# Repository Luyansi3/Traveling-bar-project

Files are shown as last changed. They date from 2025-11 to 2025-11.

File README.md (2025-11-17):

# 📷 Traveling Camera Bar Project -- Arduino & Python Control System (P2I-6)

This project implements a **motorized traveling bar** for camera motion,
controlled through a Python desktop interface.\
It combines an **Arduino Mega**, an **ESP8266 Feather Huzzah**, and a
**Python Tkinter GUI** to provide real-time control, video streaming,
object tracking, media recording, and automated timelapse scenarios.

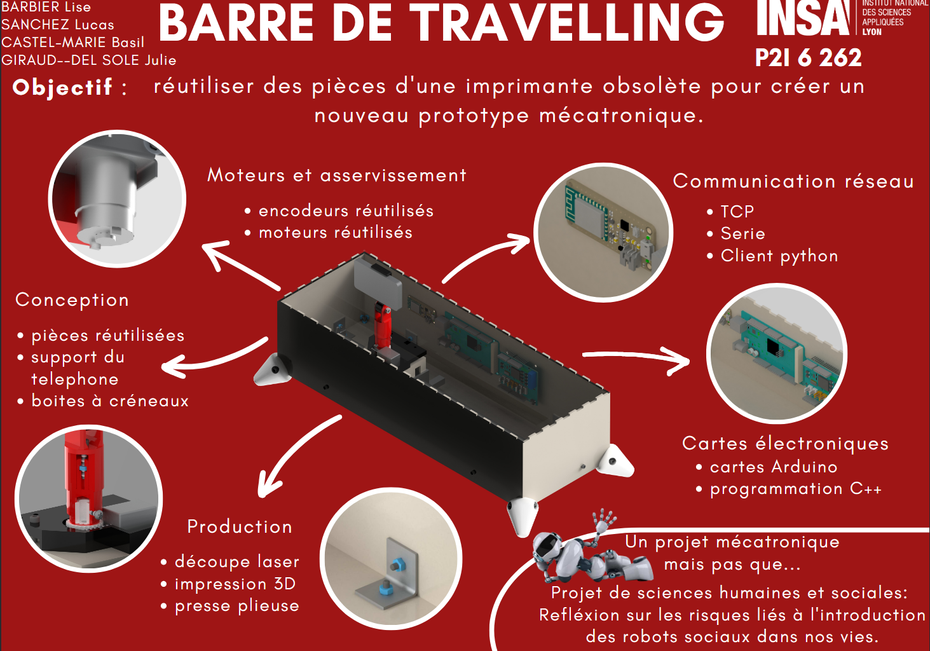
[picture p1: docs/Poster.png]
Poster


------------------------------------------------------------------------

## 🚀 Overview

The system allows precise **linear translation** and **rotation** of a
camera using two motors.\
A Python GUI connects to the ESP8266 over TCP and provides:

-   Manual control (translation & rotation)\
-   Real-time video display from an IP webcam\
-   Calibration of the linear rail\
-   Object detection & tracking (OpenCV HSV filtering)\
-   Photo & video recording\
-   Timelapse scenario automation\
-   Live feedback of motor positions from the Arduino Mega

Communication chain:

    PC (Python GUI) ⇄ TCP ⇄ ESP8266 (Wi-Fi) ⇄ Serial ⇄ Arduino Mega 2560

------------------------------------------------------------------------

# 🧠 System Architecture

## 1. Python Application (`Client.py`)

The Python program provides the full control interface.

### 🖥 `App` Class

Handles:

-   GUI (Tkinter)
-   TCP connection to ESP8266
-   Real-time video display (OpenCV)
-   Motor control buttons
-   Scenario builder (timelapse & video)
-   Threaded message reception from ESP8266
-   Object detection & tracking
-   Media recording (photos/videos)

Commands sent to the ESP8266 all begin with a structured header, for
example:

    /MEGA /MOTORA <speed>;
    /MEGA /POS ...
    /MEGA /TL <posA> <posB>;

### 📸 `MyCamera` Class

Responsible for:

-   Connecting to the IP webcam (iVCam or local webcam)
-   Returning raw frames to the UI
-   Writing video files
-   Saving photos
-   Managing resolution, FPS, and codec (XVID)

------------------------------------------------------------------------

## 2. ESP8266 Program (`Code_ESP.ino`)

The Feather Huzzah acts as a **TCP server**.

Its responsibilities:

-   Connect to a configured Wi-Fi network\
-   Accept incoming TCP connections from the PC\
-   Create a **serial bridge** between Python and the Arduino Mega\
-   Forward commands and feedback in both directions\
-   Identify and forward messages using headers:
    -   `/ORDI` → PC → Mega\
    -   `/MEGA` → Mega → PC

The ESP uses **SoftwareSerial** on pins 13 and 15 because I²C
communication was unreliable.

------------------------------------------------------------------------

## 3. Arduino Mega Program (`Code_MEGA.ino`)

The Mega manages the motors and reads the encoders.

Main features:

### 🧭 Calibration

-   Moves the motor until the mechanical limit is reached\
-   Detects plateau in encoder readings\
-   Sets the encoder value to **0** (translation origin)

### ⚙️ Motor Control

Receives commands such as:

    /MOTORA <speed>;
    /MOTORB <speed>;
    /TL <posA> <posB>;

Then:

-   Converts centimeters to encoder units\
-   Ensures setpoints remain in safe range\
-   Applies **P-control** (future upgrade to PI-control)\
-   Sends back motor position every 2 seconds using:

```
    /POSA <value>
    /POSB <value>
```

------------------------------------------------------------------------

# 📡 Communication Protocols

### **1. TCP (PC ↔ ESP8266)**

-   PC is the client\
-   ESP8266 is the server\
-   Allows command transmission & status feedback

### **2. Serial (ESP8266 ↔ Arduino Mega)**

-   Implemented via SoftwareSerial\
-   Required because I²C was unreliable\
-   Header-based routing

Example:

    /ORDI /MOTORA 120;

### **3. IP Webcam (PC ↔ Smartphone)**

The Python app retrieves the video stream using OpenCV from iVCam.

------------------------------------------------------------------------

# 🕹 Python GUI Features

### ✔ Manual Control

-   Translate left/right\
-   Rotate left/right\
-   Adjustable motor speed\
-   Progressive acceleration & deceleration for smooth motion

### ✔ Calibration

-   Automatic zeroing of the translation axis

### ✔ Real-Time Video + Object Tracking

-   HSV-based color detection\
-   On-frame markers\
-   Automatic correction commands sent every 300 ms

### ✔ Timelapse Generator

-   Define duration\
-   Select total rotation\
-   Set time interval between photos\
-   Automated movement + shooting\
-   Progress bar showing carriage movement

### ✔ Media Recording

-   Take photos (JPG)\
-   Start/stop video recording (AVI)

------------------------------------------------------------------------

# 📁 Project Structure

    /Client.py        → Python GUI
    /Code_MEGA.ino    → Arduino Mega firmware
    /Code_ESP.ino     → ESP8266 firmware

------------------------------------------------------------------------

# 🛠 Hardware Requirements

-   Arduino Mega 2560\
-   ESP8266 Feather Huzzah\
-   2× DC motors with motor drivers\
-   Linear rail + rotary stage\
-   Encoders\
-   Smartphone (iVCam) or USB webcam\
-   Computer with Python 3

------------------------------------------------------------------------

# 🧩 Software Requirements

### **Python**

-   Python 3.8+
-   Tkinter
-   OpenCV
-   Numpy
-   PIL (Pillow)

### **Arduino**

-   SoftwareSerial\
-   Encoder library\
-   WiFi libraries for ESP8266

------------------------------------------------------------------------

# ▶ How to Run

### **1. Flash the boards**

Upload: - `Code_MEGA.ino` to the Arduino Mega\
- `Code_ESP.ino` to the ESP8266

### **2. Connect devices to the same Wi-Fi network**

(iVCam phone + PC + ESP8266)

### **3. Run the Python app**

``` bash
python Client.py
```

### **4. Enter the ESP8266 IP address in the GUI**

Click **Connect**.

### **5. Start moving the camera!**

------------------------------------------------------------------------

# 📸 Media & Documentation

## 🔌 Wiring Diagram

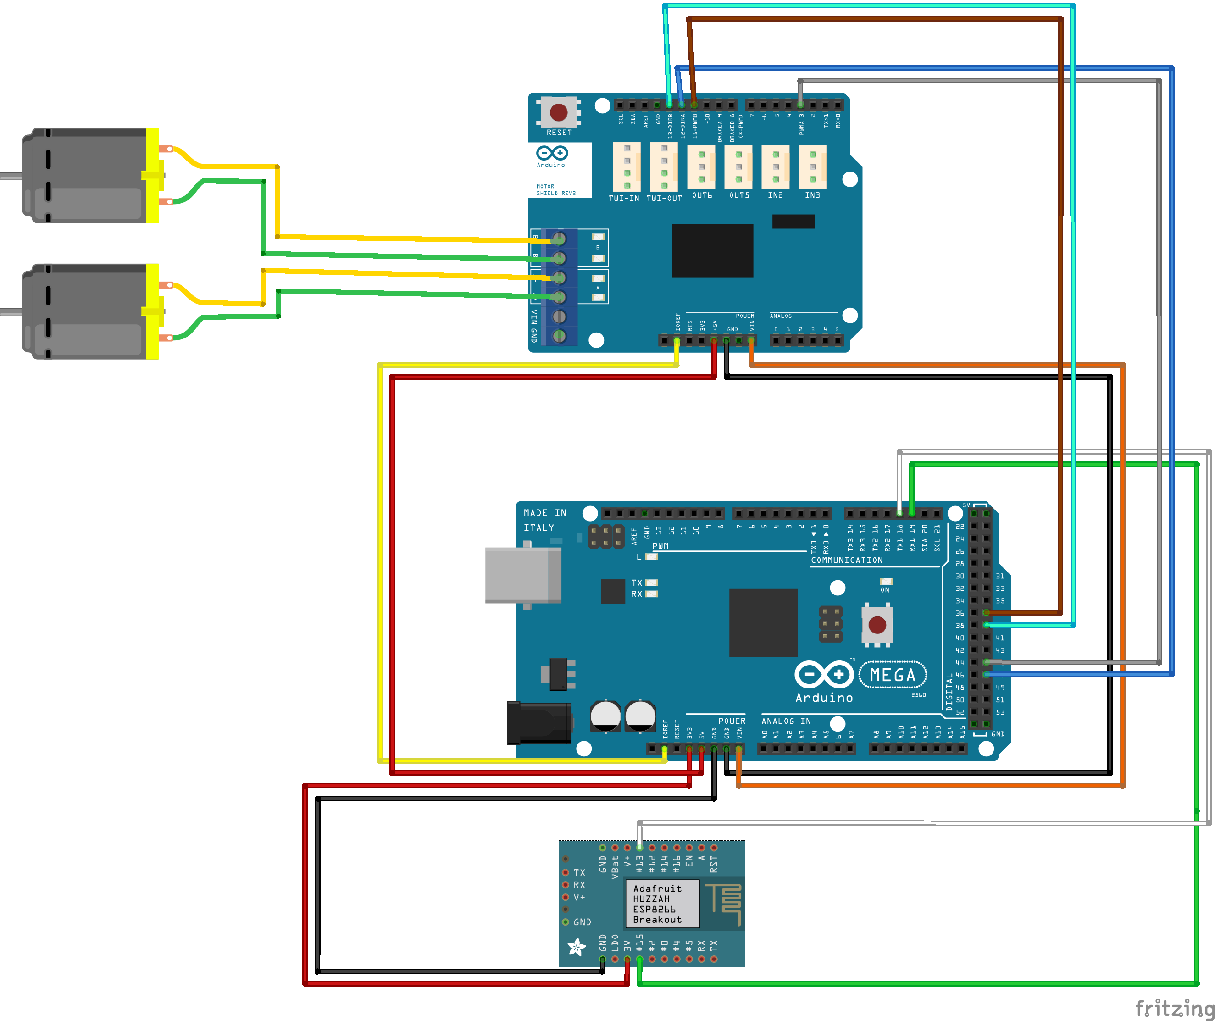
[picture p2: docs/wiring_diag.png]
Wiring Diagram


## 🎬 Demonstration Video

Demo Video

------------------------------------------------------------------------

# 🛠 Future Improvements

-   Upgrade P-control to PI-control\
-   Better object-tracking using ML models\
-   Stabilization algorithms\
-   Automatic timelapse video generation\
-   GUI redesign with PyQt or custom widgets

------------------------------------------------------------------------

# 🙌 Contributors

Lise Barbier, Basile Castel-Marie, Julie Giraud--Del Sole & Lucas Sanchez.

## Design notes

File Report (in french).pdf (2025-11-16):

# P2i6 – 262 : Réemploi d’imprimantes

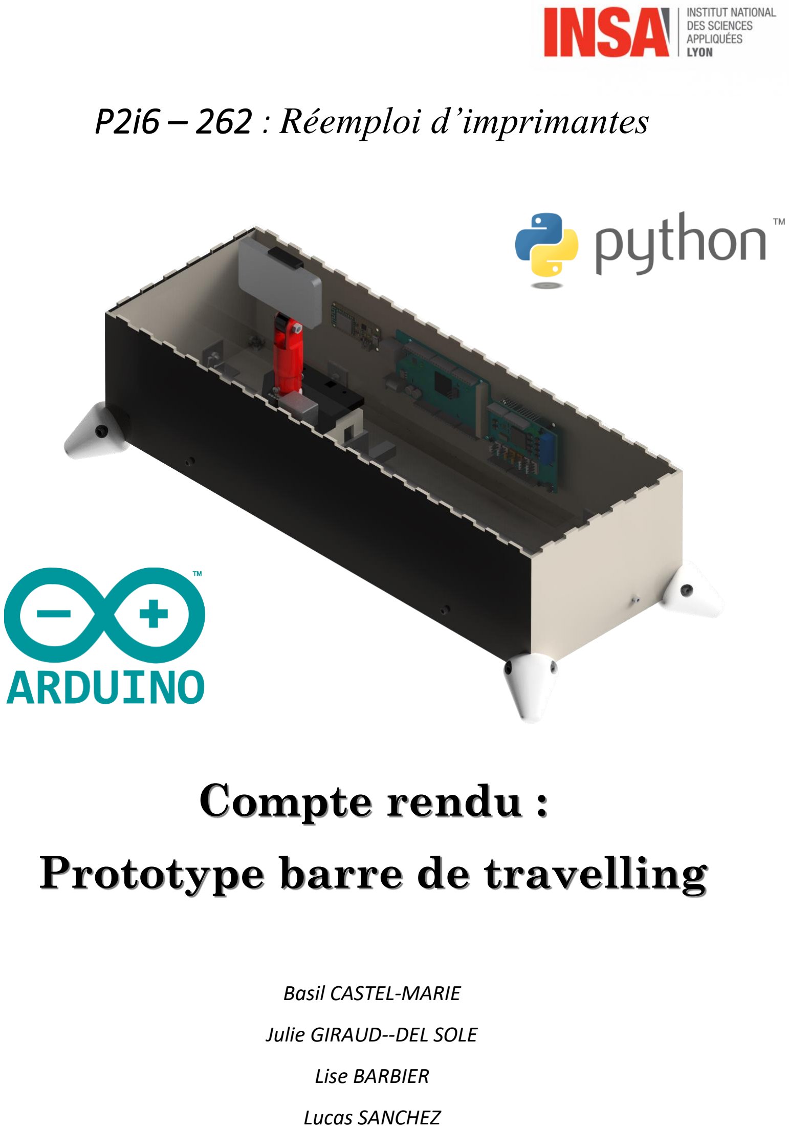
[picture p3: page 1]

# Compte rendu :

# Prototype barre de travelling

### Basil CASTEL-MARIE

### Julie GIRAUD--DEL SOLE

### Lise BARBIER

### Lucas SANCHEZ

Basil CASTEL-MARIE Julie GIRAUD--DEL SOLE Lucas SANCHEZ Lise BARBIER

Page 1 sur 19

## Compte rendu P2i6 : Barre de travelling

## Table des matières

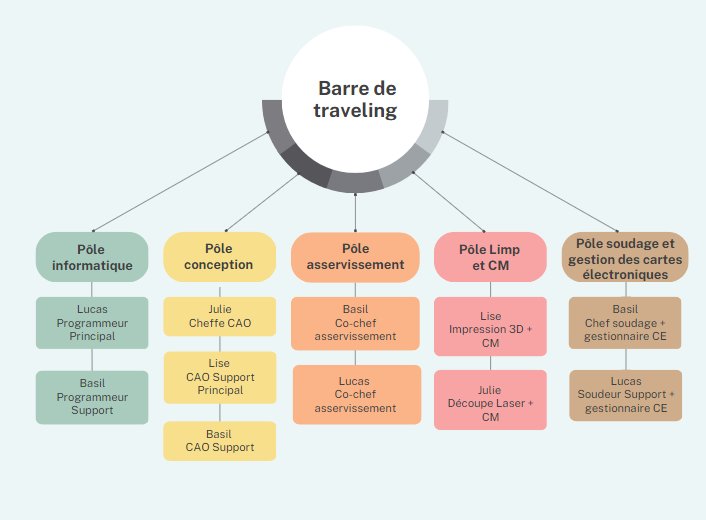
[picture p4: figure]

Page 2 sur 19

## I. Objectif

Notre objectif était de créer une barre de travelling utilisable avec un smartphone. Le smartphone doit pouvoir prendre des vidéos en effectuant un déplacement transversal et une rotation sur lui-même (asservissement des moteurs). Les mouvements du support de smartphone doivent être pilotés à distance sur un ordinateur (communication réseau TCP et série).

## II. Organigramme du groupe

## III. Journal de suivi

Remarque : Ce journal de suivi ne donne qu’une idée générale de la répartition des tâches au cours des séances et n’est pas exhaustif. Chaque membre du groupe a été totalement impliqué pour mener à bien ce projet.

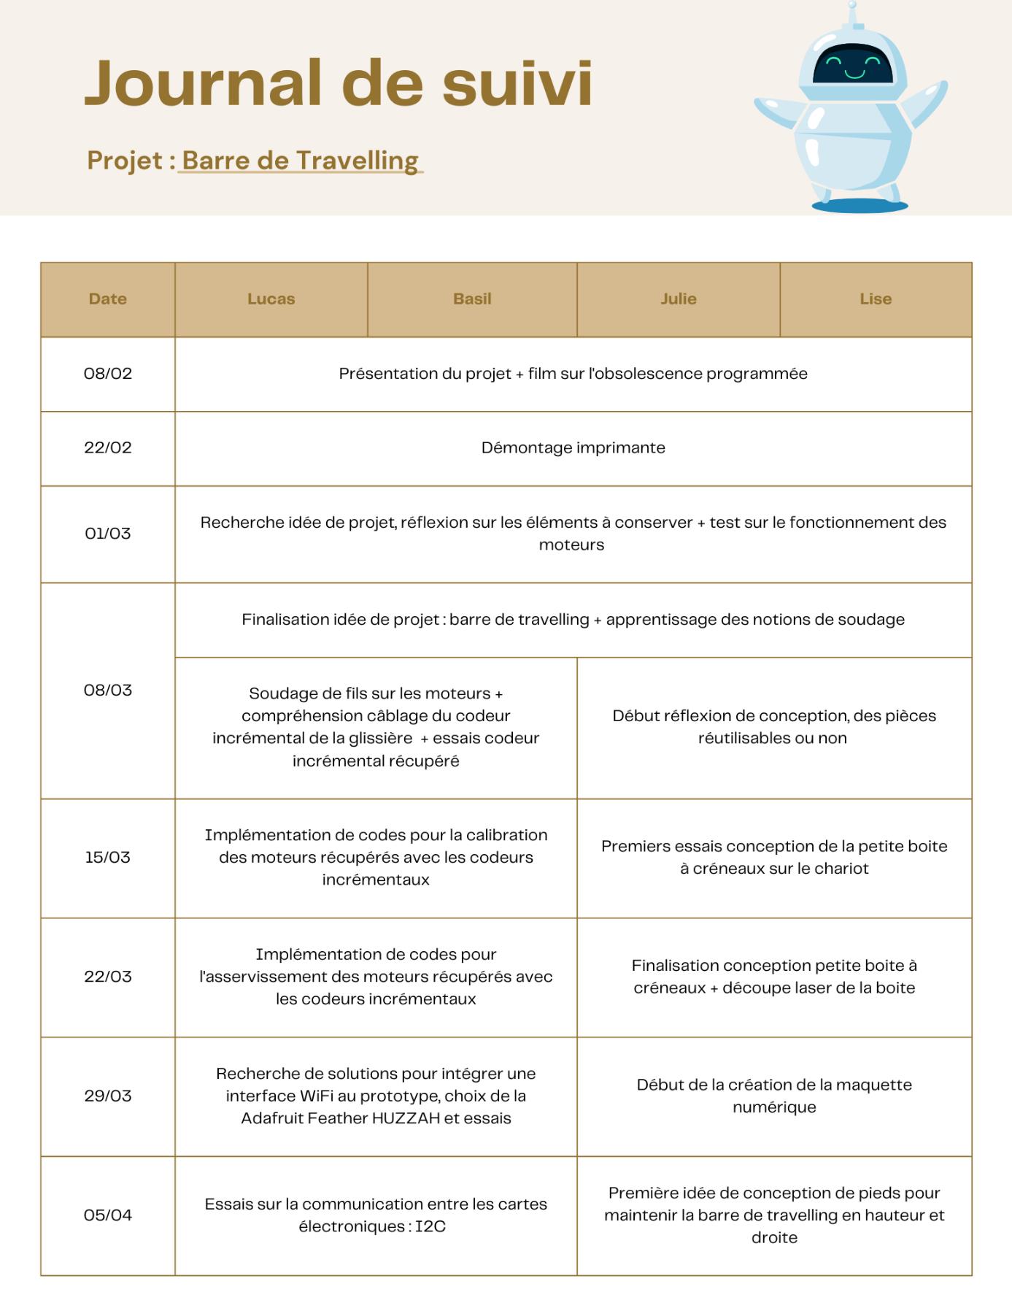
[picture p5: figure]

Page 3 sur 19

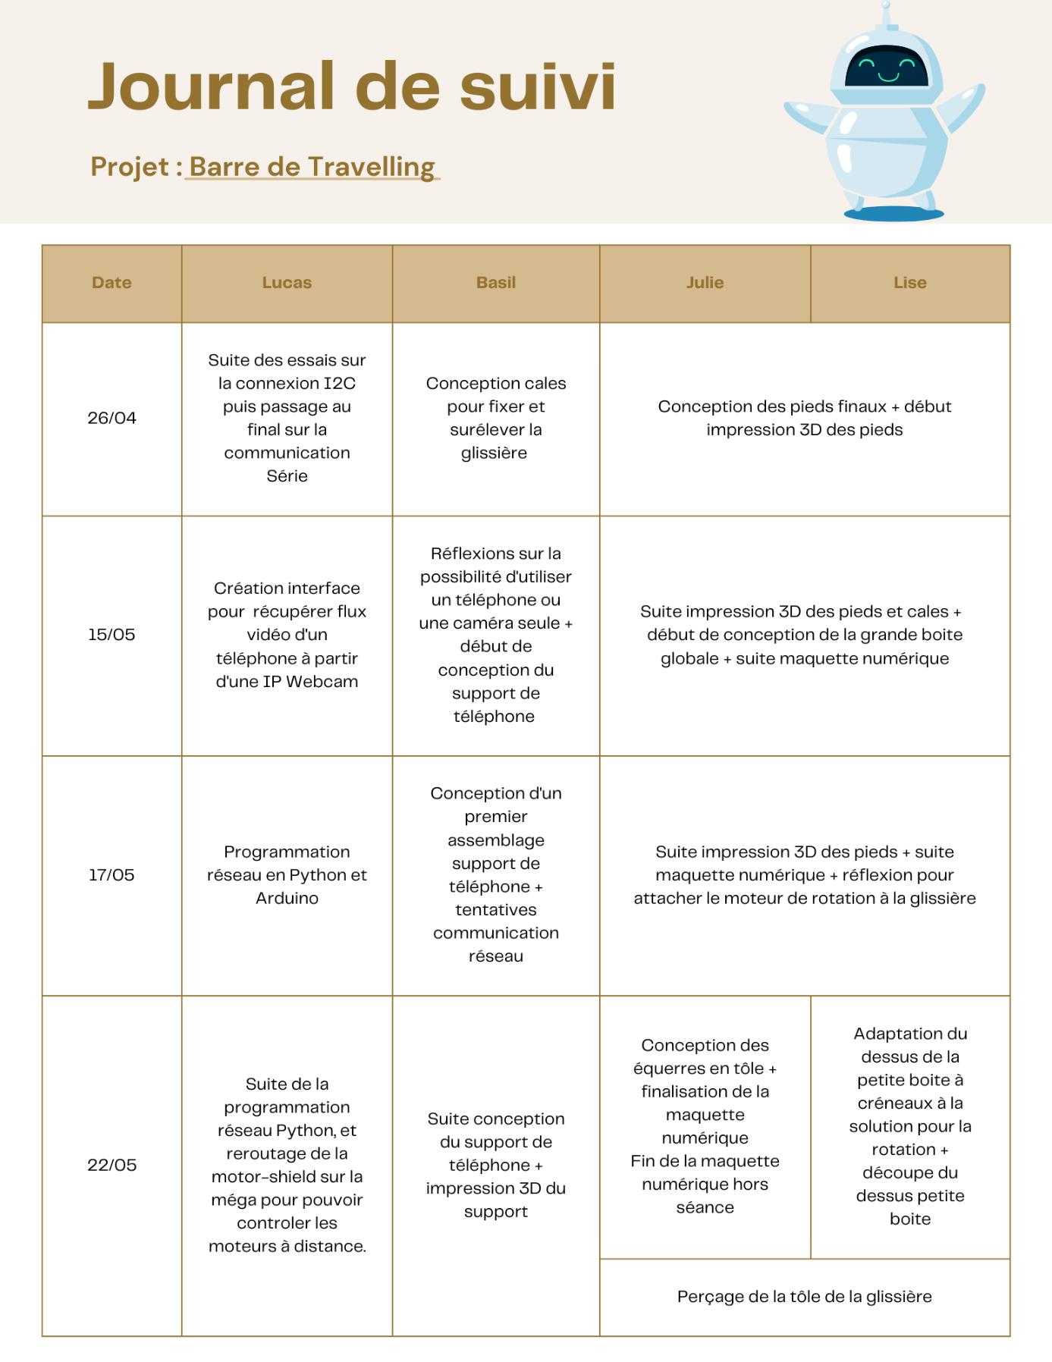
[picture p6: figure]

Page 4 sur 19

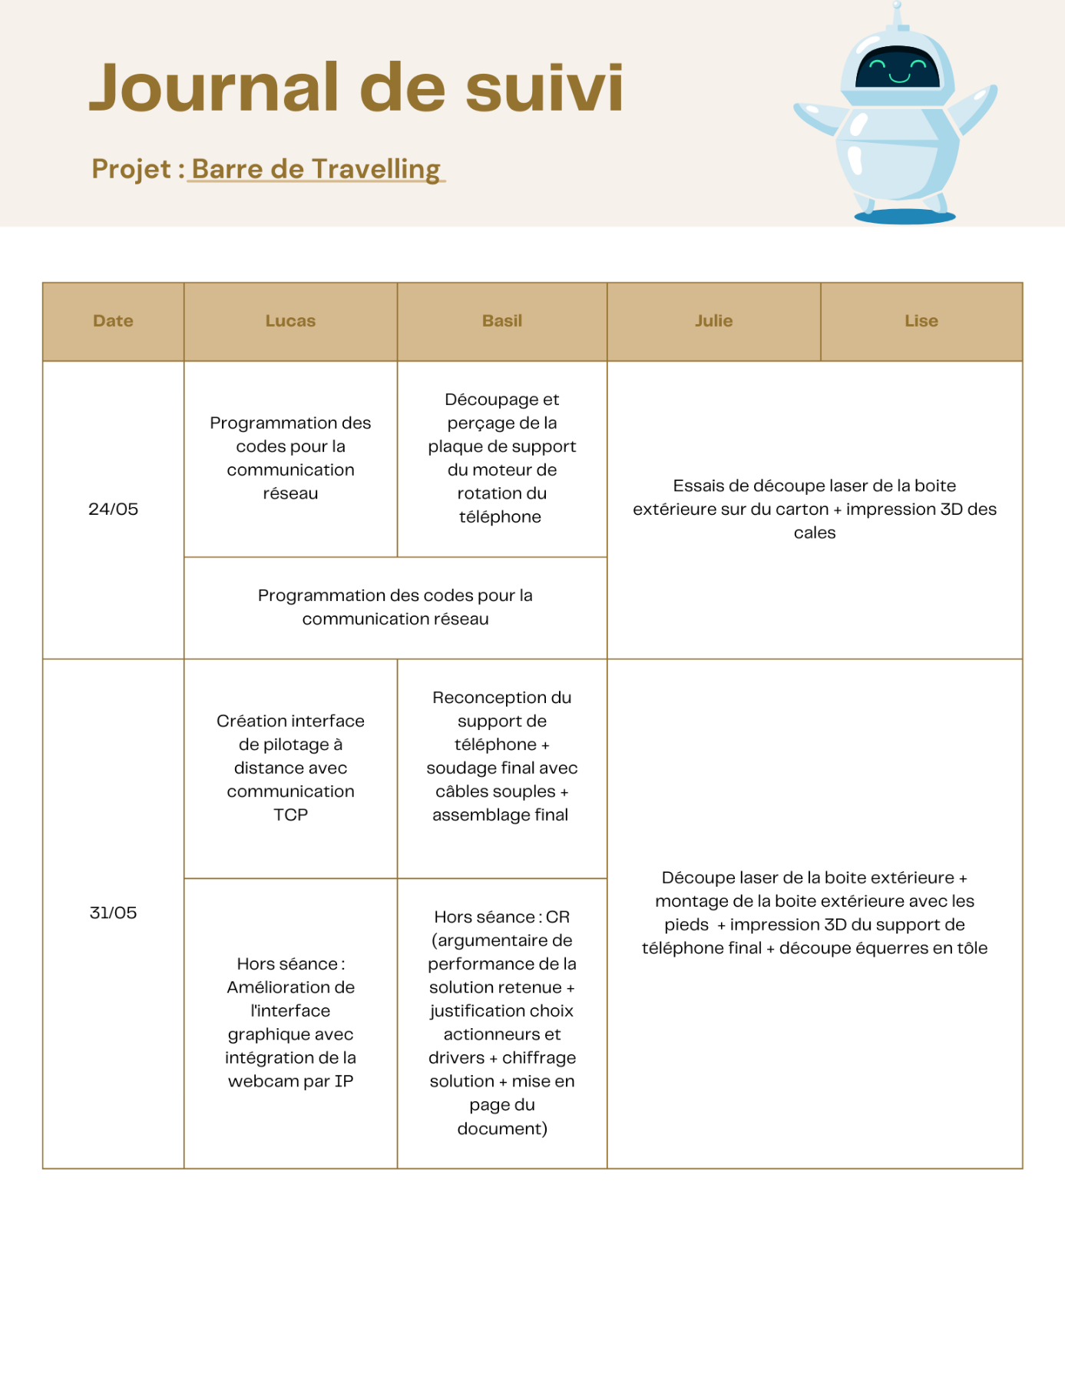
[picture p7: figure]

Page 5 sur 19

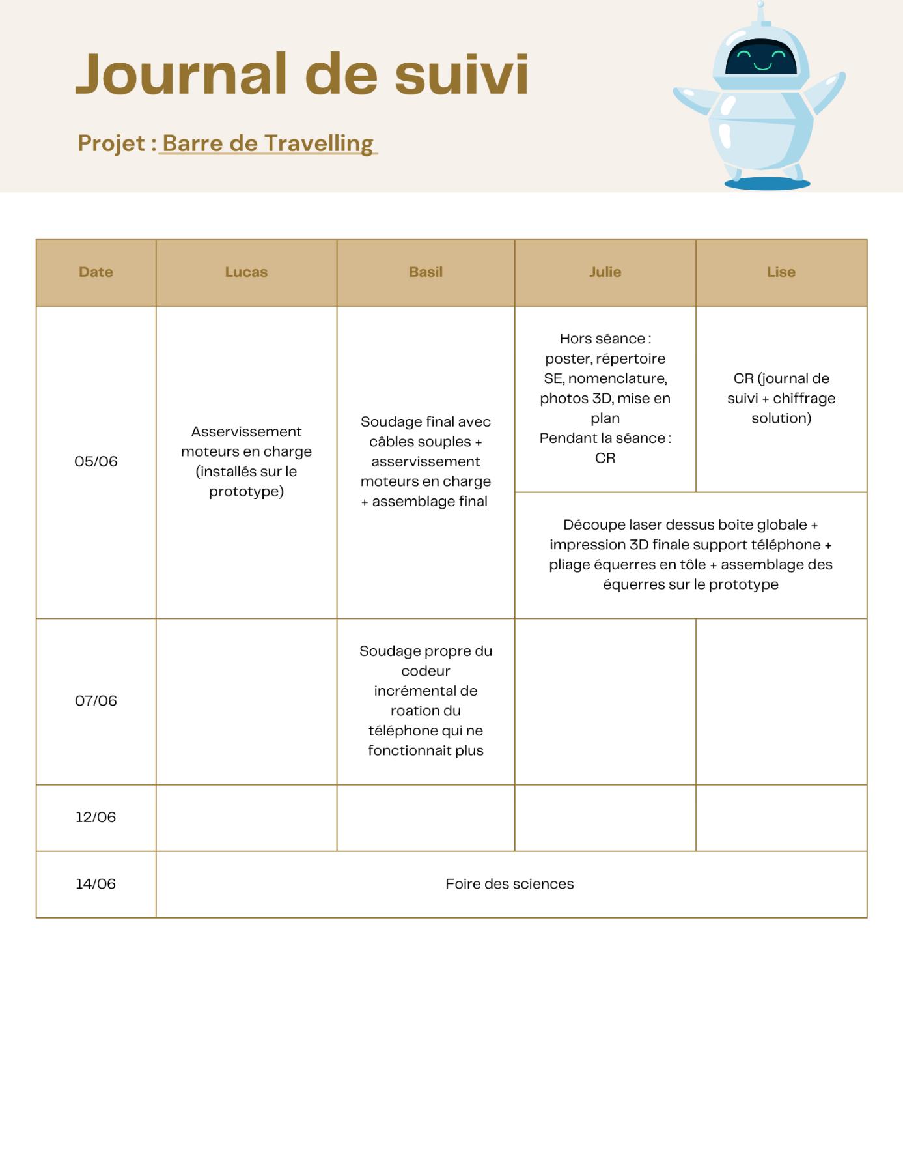
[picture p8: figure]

Page 6 sur 19

Page 7 sur 19

## IV. Argumentaire de performance de la solution retenue

### IV.1. Réutilisation des composants

Après démontage de l’imprimante défectueuse, nous avons identifié les composants utiles à notre projet.
Nous avions besoin d’une glissière sur laquelle translate une plateforme qui supporte le téléphone. Nous avons donc gardé la glissière de l’imprimante équipée d’une courroie, d’un moteur et d’un codeur incrémental sur une plateforme. Nous avons aussi gardé une autre petite plateforme équipée elle aussi d’un moteur, d’un codeur incrémental et surtout d’un engrenage vertical. Nous disposons donc grâce à l’imprimante de tous les capteurs et actionneurs nécessaires à notre projet. Pour maintenir le smartphone, nous avons récupéré les mâchoires d’une perche à selfie.

### IV.2. Choix des matériaux

La glissière et les composants électroniques de notre prototype sont légers. Nous avons donc choisi de concevoir des pièces légères pour le bâti et la transmission du mouvement. Le bâti est en fibre de bois (MDF 3 mm) et les pièces de support et de transmission mécanique sont en ABS. Seul le dessus de la boîte principale est en PMMA 3 mm pour permettre à l’utilisateur de voir l’intérieur du prototype avec les composants électroniques, les câbles, les capteurs et les actionneurs.
Afin de solidifier le bâti, nous avons également conçu des équerres en acier S235. Elles solidarisent les faces de la boîte à créneaux générale.

### IV.3. Conception

Nous avons utilisé la découpe laser pour concevoir les boîtes à créneaux générale et la boîte de la glissière. Ces boîtes ont été conçues en CAO de sorte à permettre d’ajouter des pieds au prototype, de faire passer les câbles électriques et d’insérer les vis pour positionner les éléments du prototype. Le boîte générale (bâti) repose sur 4 pieds en forme de cône imprimés en 3D. Ils s’insèrent aux quatre coins de la face de dessous de la boîte générale et assurent l’équilibre de l’ensemble.
Les cales de glissière ont-elles aussi été imprimées en ABS. Elles permettent de fixer la glissière au bâti et de la surélever.
Le support de téléphone a été conçu en CAO et imprimé en deux parties. La partie inférieure est constituée d’un alésage femelle avec dentures par révolution qui s’adapte précisément à l’engrenage plastique récupéré dans l’imprimante. La partie supérieure du support de téléphone s’adapte aux mâchoires récupérées sur la perche à selfie.
Nous avons utilisé la presse plieuse et la découpe laser pour concevoir les équerres en acier. Nous avons aussi percé des trous dans la glissière en tôle et dans les supports récupérés sur l’imprimante pour les adapter à notre prototype.

### IV.4. Assemblage

Nous voulions concevoir un prototype démontable pour pouvoir lui apporter d’éventuelles modifications ou améliorations.
Nous avons donc choisi de privilégier les liaisons complètes par boulonnage. Dans les pièces imprimées en 3D, nous avons noyé les écrous pour faciliter le montage et le démontage.
La liaison entre la partie inférieure du support de téléphone et l’engrenage est assurée par les cannelures mais aussi par quatre vis de pression auto-taraudeuses. Elles sont nécessaires en raison de la masse du téléphone maintenu en hauteur, elles permettent d’éviter le jeu résultant et donc de stabiliser la vidéo.
Les créneaux des boîtes permettent d’assembler les faces et d’assurer la mise et le maintien en position. Les équerres et les pieds permettent d’assurer un maintien en position secondaire.

Page 8 sur 19

### IV.5. Choix des composants électroniques

Nous avions besoin de piloter deux moteurs asservis, nous avons donc utilisé le Motor Shield (explication du choix développé.
Nous disposons aussi de deux codeurs incrémentaux sur deux cartes électroniques récupérés sur l’imprimante.
Pour communiquer en WiFi avec un ordinateur client, nous avons utilisé la carte Adafruit Feather HUZZAH équipée du module WiFi ESP8266. La Feather HUZZAH n’est pas simplement équipée d’un module WiFi, c’est un microcontrôleur à part entière dans lequel on peut implémenter un code Arduino. Elle peut aussi communiquer en série avec d’autres microcontrôleurs ce qui en fait une interface réseau sans fil idéale pour l’ensemble de l’installation électronique du prototype.
Pour gérer tous ces composants électroniques, nous avons choisi d’utiliser la carte Arduino MEGA Rev3. Par rapport à une Arduino UNO classique, cette carte a plus de pins disponibles pour les périphériques et une plus grande mémoire flash pour pouvoir stocker un code plus lourd. Notre choix se justifie surtout par la nécessité d’avoir 4 pins d’interruption pour les deux codeurs incrémentaux. La UNO n’en possède que 2, alors que la MEGA en a 6.

### IV.6. Communication entre les composants électroniques

Pour communiquer entre la MEGA et la Feather HUZZAH, nous avons choisi la communication série asynchrone. Elle ne nécessite que deux câbles et permet d’envoyer et de recevoir des caractères ASCII sous forme d’octets.

### IV.7. Pilotage à distance

Pour utiliser la caméra du smartphone, nous utilisons l’application ivCam installée sur l’ordinateur et le smartphone qui permet de convertir la caméra en Webcam avec une adresse IP dans le réseau local.
Nous avons choisi de faire de la Feather HUZZAH un serveur TCP en Arduino, nous avons donc créé un client TCP Python sur ordinateur. Cet ordinateur se connecte à la Feather HUZZAH sur un réseau WiFi local. Pour faciliter son utilisation, nous avons créé une interface graphique avec la bibliothèque Tkinter. Depuis cette interface graphique, on peut lancer la caméra du téléphone, faire pivoter et déplacer le téléphone sur la barre de travelling tout en visualisant la vidéo de la caméra.

### IV.8. Alimentation

Notre prototype est alimenté par le secteur avec une alimentation 12V 3A pour pouvoir alimenter simultanément toutes les cartes électroniques depuis la MEGA.

## V. Analyse critique des choix des actionneurs & capteurs avec drivers associés

D’un point de vue mécatronique, le principal défi de notre projet est l’asservissement des moteurs (celui pour le déplacement transversal et celui pour la rotation du support de téléphone). On a réutilisé deux des trois moteurs à courant continu de notre imprimante et leur codeur incrémental. L’utilisation des moteurs CC a plusieurs avantages pour notre prototype. Contrairement à un moteur pas à pas, un moteur CC ne consomme pas d’énergie à l’arrêt et est moins volumineux. En plus, avec un moteur CC, nous mettons en œuvre nous-même l’asservissement et nous gérons directement sa position grâce au codeur incrémental, ce qui nous permet un suivi de position. Avec des moteurs CC et leur codeur incrémental, nous avons un bon contrôle du mouvement.

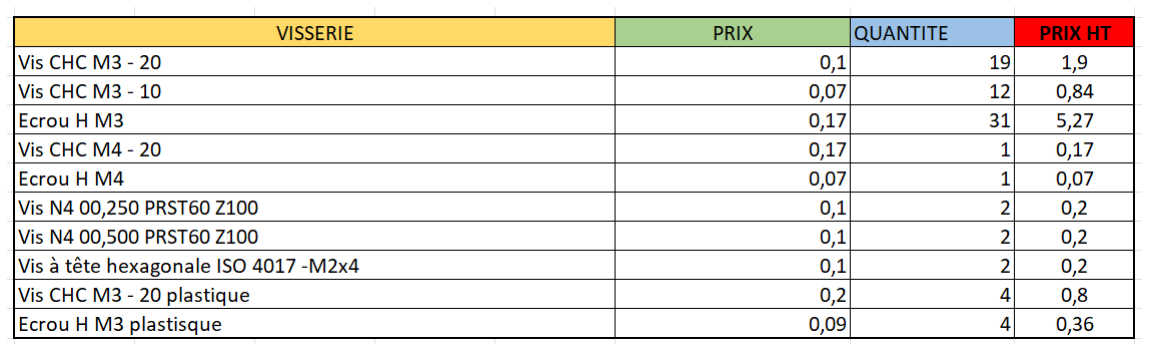
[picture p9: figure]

Page 9 sur 19

Pour gérer ces moteurs, nous avons choisi le Motor Shield Rev3 Arduino équipé du driver L298. Ce driver permet de fournir un courant maximal de 2A contrairement à la carte Arduino seule qui ne peut fournir que 40 mA au maximum ce qui est insuffisant pour un moteur. En plus, le driver L298 de du Motor Shield permet de gérer facilement deux moteurs indépendamment en envoyant des commandes de direction et de vitesse (signal PWM) et permet aussi de mesurer l’intensité consommée.
Pour gérer les codeurs incrémentaux, nous utilisons la librairie Encoder qui nous permet de lire et de mettre à 0 la position radiale du moteur à un instant donné (pour la calibration).

## VI. Chiffrage de la solution proposée

Total électronique : 71€75

Total matériaux : 19€78

Total visserie : 10€01
Prix total du prototype : 101€54 ce qui est inférieur à la limité imposée à 150€ par prototype.

## VII. Explications Arduino

### VII.1. Feather HUZZAH (ESP8266)

Dans la Feather HUZZAH il y a une connexion série qui est faite avec la Méga. La Feather HUZZAH se connecte d’autre part au réseau WiFi local. Ensuite, elle attend la connexion d’un client (le PC). Puis en fonction de ce que le PC envoie sur le réseau WiFi (requête TCP), elle transmet le message à la MEGA. Si la MEGA envoie en message, la Feather HUZZAH le transmet au PC en réponse TCP sur le réseau WiFi local (le tout en fonction des entêtes).

Page 10 sur 19

### VII.2. Arduino MEGA Rev3

Le code implémenté dans la MEGA lit les données de l’encodeur de la glissière. La MEGA se sert des données de l’encodeur pour effectuer la calibration de la position du support de téléphone. Le moteur va dans une direction et, lorsqu’il arrive en butée contre la glissière, il force et ne bouge plus donc la position lue par l’encodeur reste fixe pendant plus de 10 millisecondes. L’encodeur est donc initialisé à 0 pour cette position.
D’autre part, la MEGA attend des messages de la Feather HUZZAH pour savoir quel est le moteur activé (/MOTOR, …) et quelle est la commande (position d’arrivée et direction de déplacement). Puis, une conversion de la consigne est faite (passage de centimètres à l’unité de l’encodeur) avec une vérification de la consigne.
Ensuite un asservissement en P est fait pour le moteur. La position est ensuite renvoyée au PC, toutes les 2 sec.
Au moment de la rédaction de ce compte rendu, la calibration, l’asservissement et l’envoi de commandes ne sont pas encore mis au point pour la rotation du téléphone selon la verticale mais il est également prévu à terme des les faire. Il est aussi prévu de passer d’un asservissement P à PI, déjà testé à vide et plus efficace pour notre système.

## VIII. Explications Python

Le fichier python est constitué d’une interface graphique avec 2 classes.
La première : « App » est la principale, c’est elle qui gère tous les éléments du programme. Elle permet, à l’aide de la seconde classe MyCamera, de récupérer le flux vidéo du téléphone et de l’afficher sur la fenêtre Tkinter en temps réel. L’interface permet aussi de se connecter à la Feather HUZZAH avec une adresse IP à rentrer. Ensuite, plusieurs boutons sont disponibles : la translation vers la gauche, vers la droite, la rotation vers la droite, vers la gauche et la calibration. Tous ces boutons sont reliés à des fonctions callbacks qui permettent d’envoyer un message particulier à la Feather HUZZAH. Le message est encodé en octet (code ASCII) avec l’entête /MEGA, puis /POS qui indique qu’il s’agit d’une position à modifier par exemple.
De plus, un thread tourne en parallèle, il permet de réceptionner les messages envoyés par la Feather HUZZAH sans que l’attente du message soit bloquante. Il est ensuite affiché sur la fenêtre.
A terme le programme pourra aussi permettre d’enregistrer la vidéo.

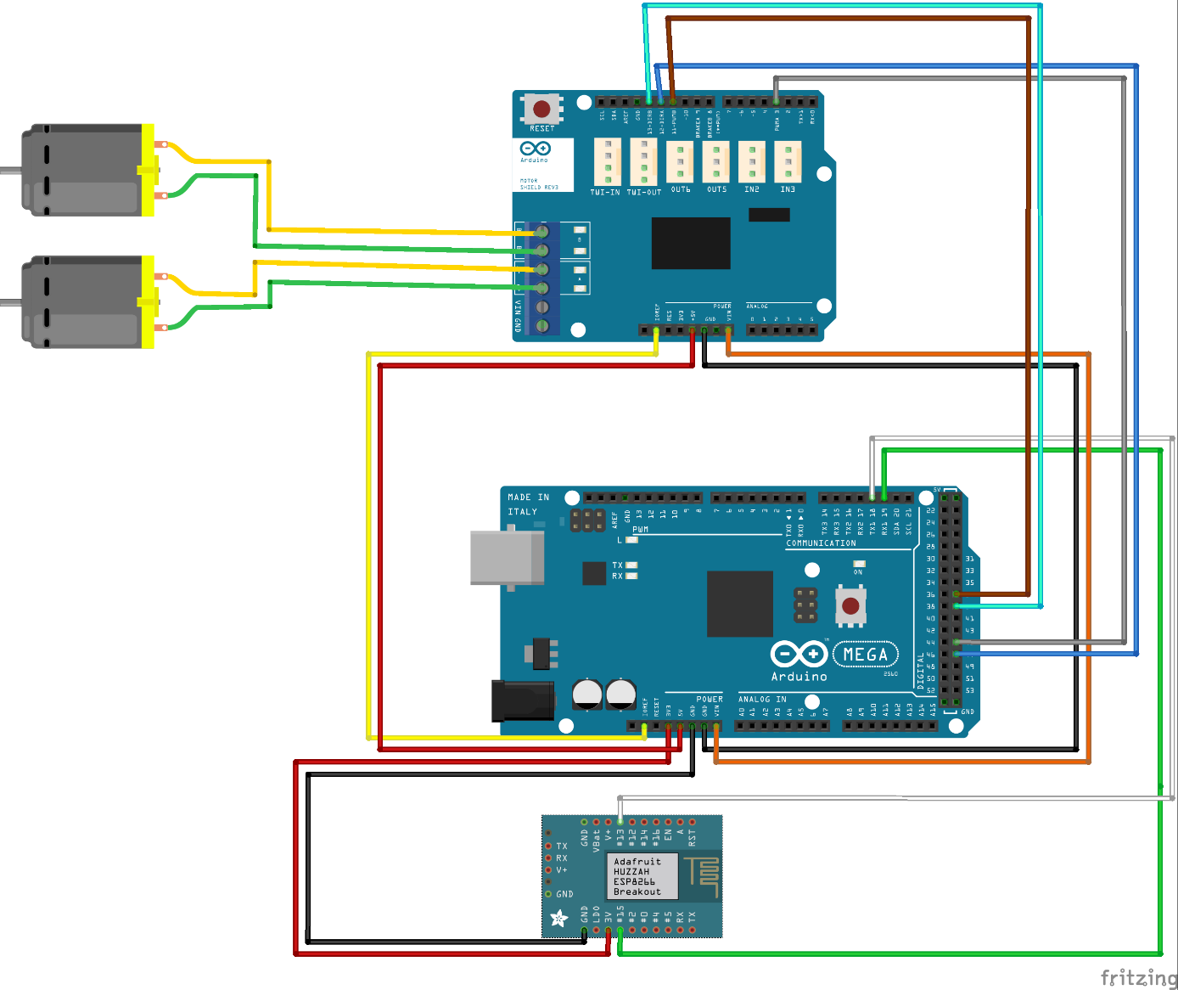
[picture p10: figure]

Page 11 sur 19

## IX. Schéma de câblage

Remarque : Les codeurs incrémentaux sont absents du schéma de câblage puisque le logiciel de création de ce schéma ne proposait pas de telles cartes. Ils sont simplement reliés au 3.3V et au GND de la MEGA. Leurs deux broches de phototransistors respectives sont branchées sur des entrées numériques de la MEGA.

## X. Protocoles de communication

### X.1. Communication TCP

- Le client est le PC, il fait tourner le programme de contrôle de la direction, de la vitesse des moteurs, et il récupère la vidéo.
-Le serveur est la Feather HUZZAH avec le module WiFi ESP8266. Elle se connecte en WiFi au même réseau que le PC. Dans notre cas il s’agira directement du PC qui créera un point d’accès réseau WiFi, ce qui permettra de récupérer facilement l’adresse IP de la Feather HUZZAH.
- Les messages transitent sous forme de paquets encodés de chaîne de caractères à octets puis décodés de octets à chaîne de caractères selon le code ASCII.
Ainsi, le PC envoie des messages concernant les commandes que doit faire les actionneurs. La Feather HUZZAH les reçoit et envoie en retour des informations sur les moteurs.

Page 12 sur 19

### X.2. Communication Série (Serial)

La connexion série qui permet de faire communiquer la MEGA et la Feather HUZZAH par deux fils. Nous avons choisi cette solution car la communication I2C ne fonctionnait pas correctement avec la Feather HUZZAH. Ainsi, nous avons créé 2 ports séries « virtuels » sur la Feather HUZZAH à l’aide de la bibliothèque Software Serial (ports 13 et 15). Ils sont ensuite raccordés aux ports serial RX1 et TX1 de MEGA.
Les messages qui transitent sont constitués d’un entête : /ORDI ou /MEGA qui permet de connaitre la destination du message.

## XI. Images 3D et rendu réaliste

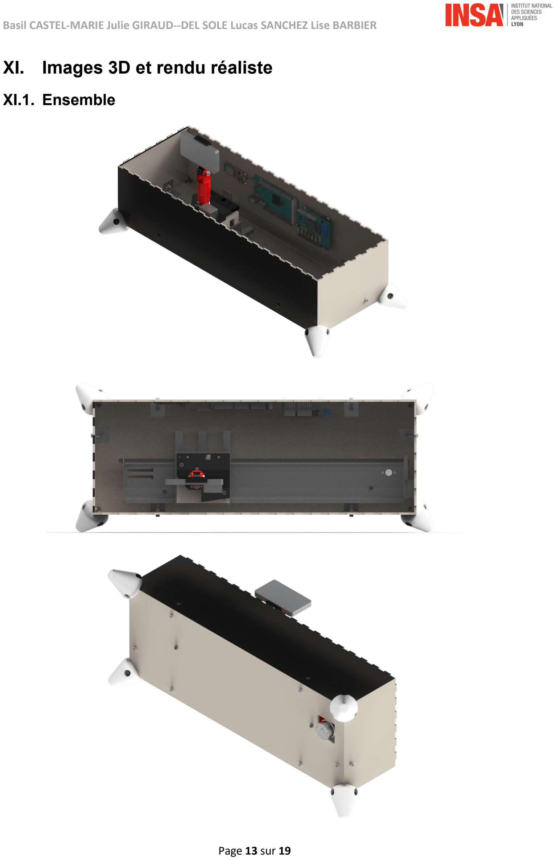
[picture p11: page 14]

Page 13 sur 19

### XI.1. Ensemble

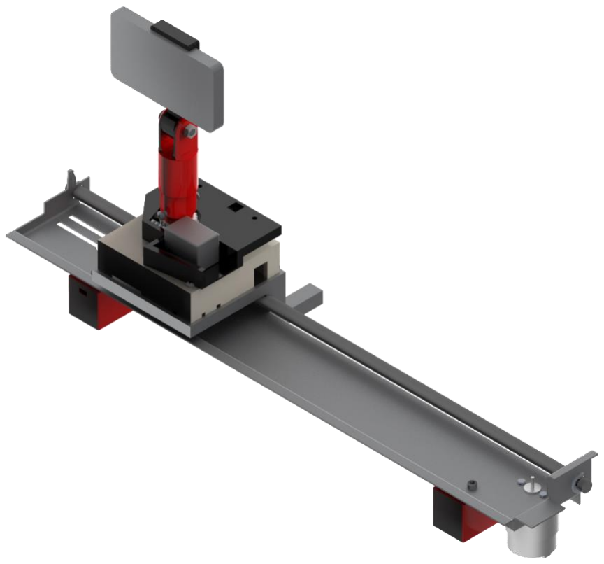
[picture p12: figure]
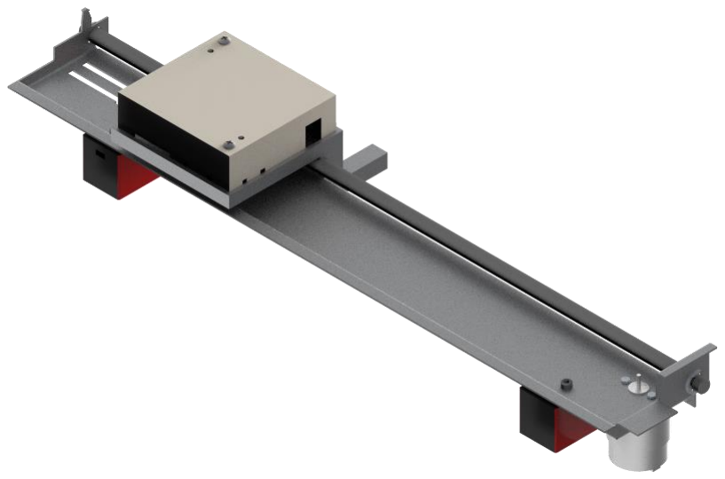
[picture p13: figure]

Page 14 sur 19

### XI.2. Déplacement du téléphone

XI.2.a. Translation

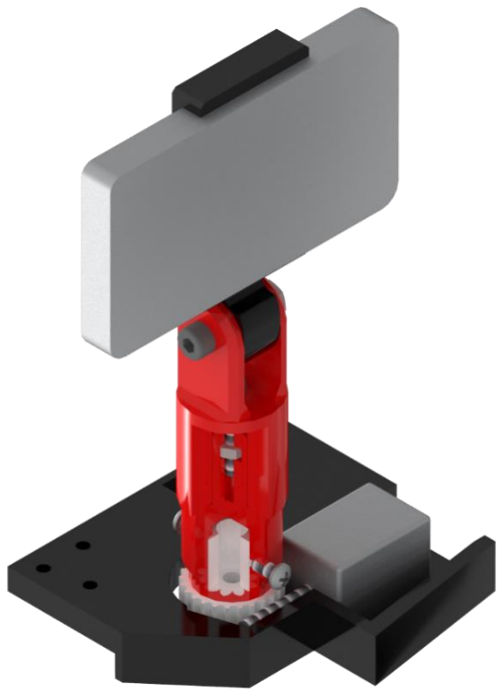
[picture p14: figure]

Page 15 sur 19

XI.2.b. Rotation

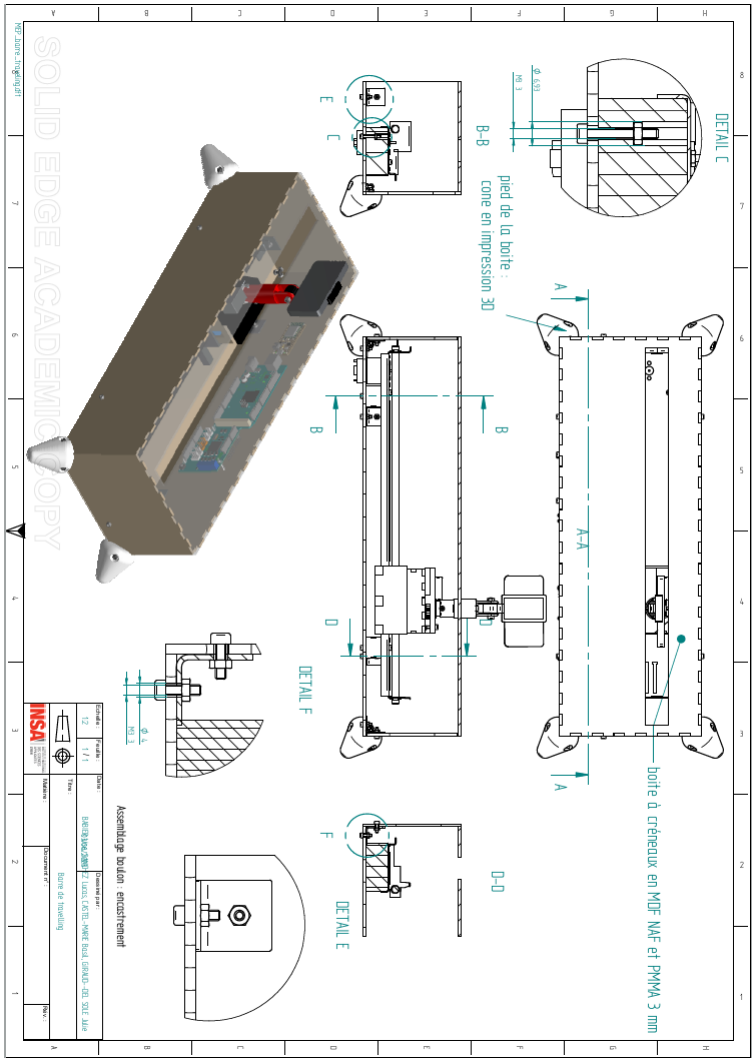
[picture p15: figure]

Page 16 sur 19

## XII. Plans d’ensemble et nomenclature

### XII.1. Plans d’ensemble

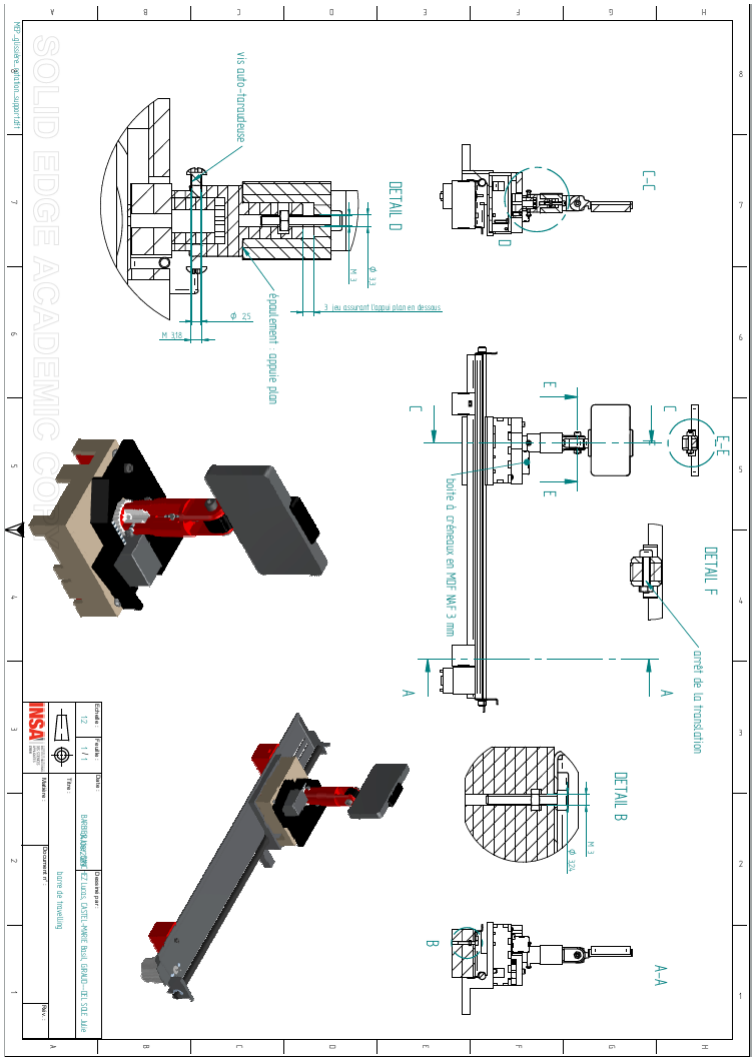
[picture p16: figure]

Page 17 sur 19

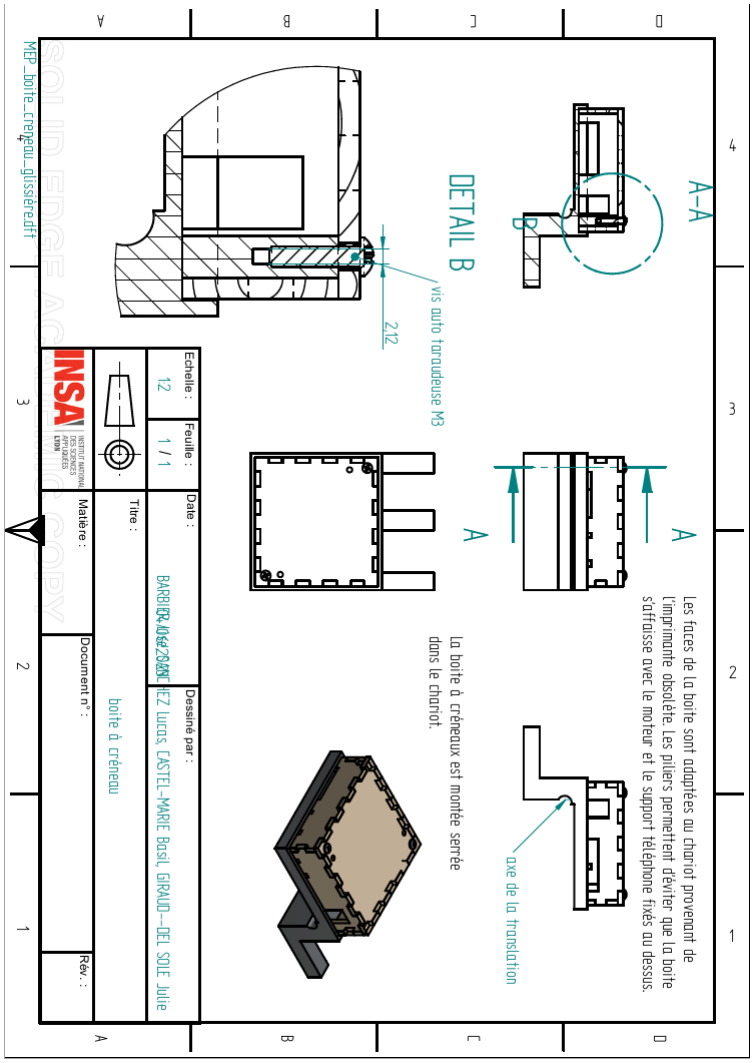
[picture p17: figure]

Page 18 sur 19

Page 19 sur 19

XII.2. | Nomenclature
19 | Vis CHC M3-20 | Acier | 40
31 | Ecrou H M3 | Acier | 39
1 | boite générale dessous | Bois, acajou | 01
1 | boite générale flan | Bois, acajou | 02
1 | boite générale bout AV | Bois, acajou | 03
1 | boite générale dessus | PMMA | 04
1 | boite générale flan G | Bois, acajou | 05
1 | boite générale bout | Bois, acajou | 06
4 | Cone pied | Plastique ABS, haute performance | 07
8 | Embout fixation Arduino | Acrylique, haute performance | 14
12 | Vis CHC M3-10 | Acier | 38
1 | Adafruit ESP8266 Feather | Acier S235 | 09
6 | equerre | Acier S235 | 10
4 | Entretoise | Acrylique, haute performance | 13
4 | Ecrou H M3 plastique | Acrylique, haute performance | 42
4 | Vis CHC M3-20 plastique | Acrylique, haute performance | 41
1 | Arduino MEGA 2560 Rev3V2 | Acier | 11
1 | Shield Motor REV3c eagle | Acier | 12
1 | tole glissière | Acier S235 | 15
1 | moteur translation | Acier S235 | 16
2 | Vis à tête hexagonale ISO 4017 - M2x4 | Acier | 43
1 | cale boite A | Plastique ABS, haute performance | 20
1 | axe glissière | Acier S235 | 17
1 | cale boite B | Plastique ABS, haute performance | 19
2 | Rondelle de retenue DIN 6799 - 6 | Acier | 18
2 | Vis N4 0.500 PRST60 Z100 | Acier galvanisé | 46
4 | Vis N4 00.250 PRST60 Z100 | Acier galvanisé | 47
1 | chariot glissière | Nylon, usage général | 21
1 | support perche selfie | Plastique ABS, haute performance | 34
1 | tige support telephone | Plastique ABS, haute performance | 35
1 | Ecrou H M4 | Acier S235 | 44
1 | Vis CHC M4-20 | Acier | 45
1 | Accroche telephone | Nylon, usage général | 36
1 | Telephone | Acier S235 | 37
1 | boite glissière dessous | Bois, acajou | 22
1 | boite glissière flan | Bois, acajou | 23
1 | boite glissière bout AV | Bois, acajou | 24
1 | boite glissière dessus | Bois, acajou | 26
1 | boite glissère flan G | Bois, acajou | 25
1 | boite glissière bout | Bois, acajou | 27
1 | pillier A | Plastique ABS, haute performance | 28
1 | support moteur rotation | Nylon, usage général | 30
1 | moteur rotation | Acier S235 | 31
1 | engrenage diamètre 21 | Nylon, usage général | 32
1 | pignon moteur diamètre 9 | Nylon, usage général | 33
1 | pilier B | Plastique ABS, haute performance | 29
Qté | Description | Matière | Rév.

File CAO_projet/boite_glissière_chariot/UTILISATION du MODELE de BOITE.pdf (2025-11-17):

# UTILISATION du MODELE de BOITE

## ADAPTER les DIMENSIONS de la BOITE

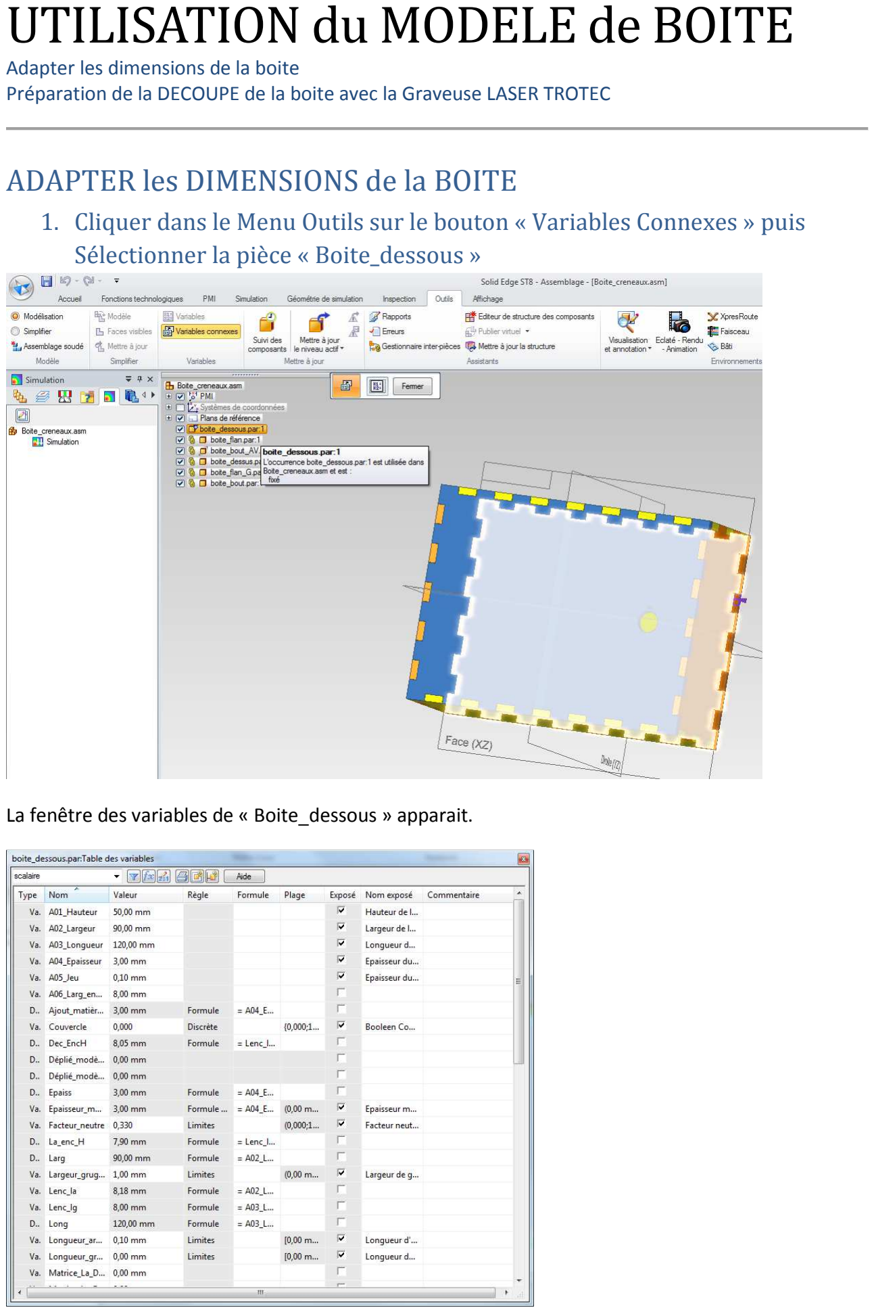
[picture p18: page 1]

Adapter les dimensions de la boite
Préparation de la DECOUPE de la boite avec la Graveuse LASER TROTEC

### 1. Cliquer dans le Menu Outils sur le bouton « Variables Connexes » puis Sélectionner la pièce « Boite_dessous »

La fenêtre des variables de « Boite_dessous » apparait.

### 2. Pour adapter les dimensions de votre boite, modifier :

A01_Hauteur : hauteur de la boite (50 mm ici)
A02_Epaisseur : épaisseur des parois (3mm ici)
A03_Largeur : largeur de la boite (90 mm ici)
A04_Longueur : longueur de la boite (120mm ici)

Les paramètres aditionnels suivant peuvent être modifiés si besoin (optionnel) :

A05_Jeu : jeu négatif (serrage) des encoches dans créneaux (0.1mm ici, fonctionne bien avec le MDF pour un assemblage sans colle).
A06_Larg_encoche : la largeur des encoches

VOIR PREPARATION de la DECOUPE LASER page suivante.

## Découpage à l’imprimante laser

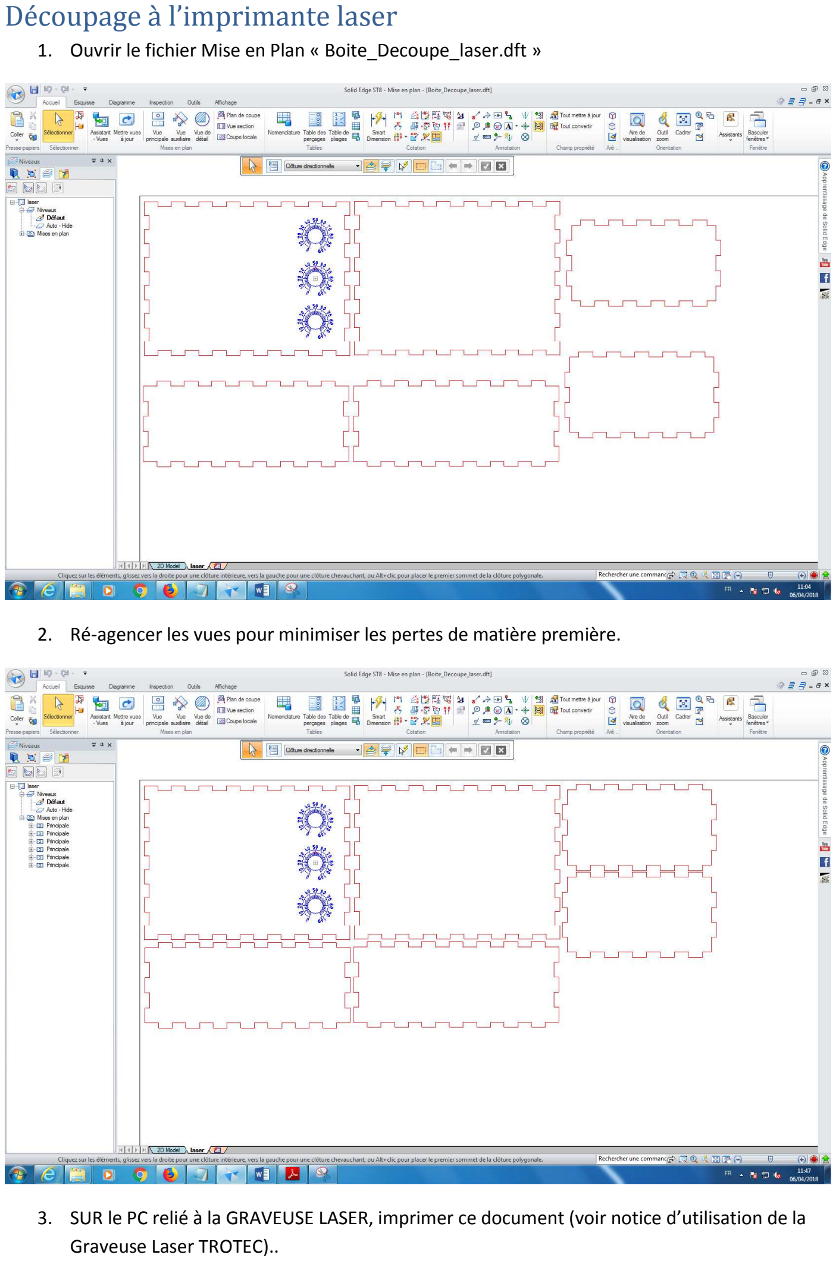
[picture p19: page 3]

1. Ouvrir le fichier Mise en Plan « Boite_Decoupe_laser.dft »
2. Ré-agencer les vues pour minimiser les pertes de matière première.
3. SUR le PC relié à la GRAVEUSE LASER, imprimer ce document (voir notice d’utilisation de la Graveuse Laser TROTEC)..

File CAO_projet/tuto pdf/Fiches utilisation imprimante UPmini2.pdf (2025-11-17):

FIMI

# MANUEL UTILISATION IMPRIMANTE UPmini 2

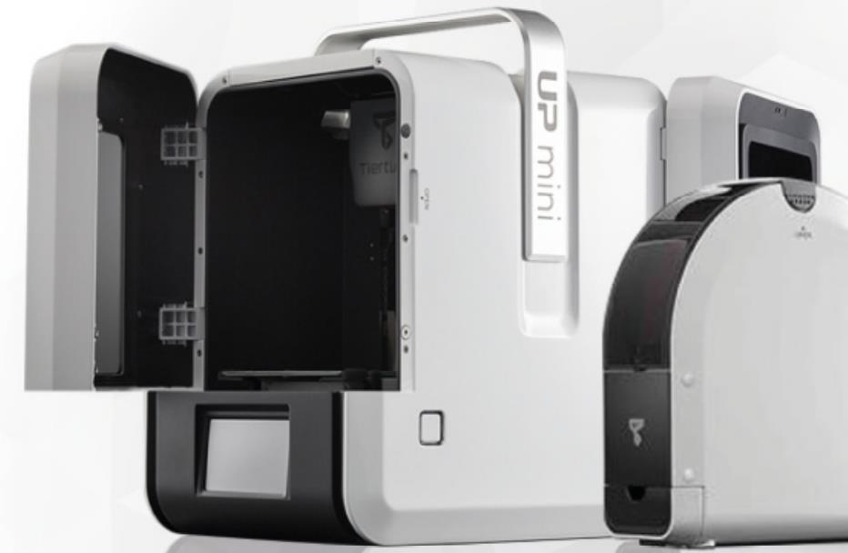
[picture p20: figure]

## Table des matières

FICHE N°9 : Calibration de l’axe Z du plateau de fabrication | 13
FICHE N°10 : Organigramme | 15

# FICHE N°1 : Export d’un fichier STL depuis SOLIDEDGE

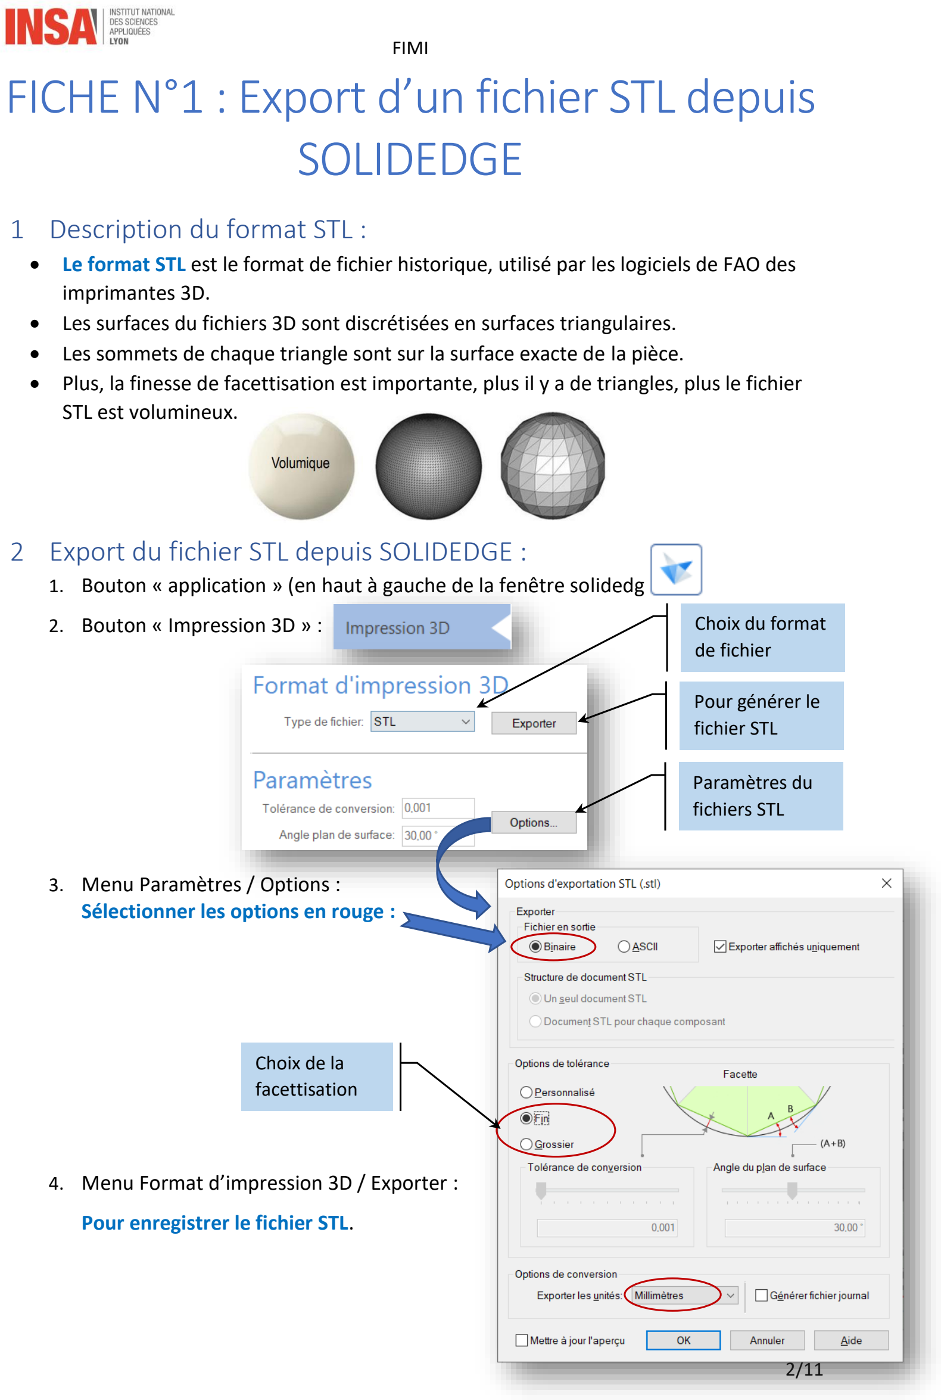
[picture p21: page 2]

## 1 Description du format STL :

- Le format STL est le format de fichier historique, utilisé par les logiciels de FAO des imprimantes 3D.
- Les surfaces du fichiers 3D sont discrétisées en surfaces triangulaires.
- Les sommets de chaque triangle sont sur la surface exacte de la pièce.
- Plus, la finesse de facettisation est importante, plus il y a de triangles, plus le fichier STL est volumineux.

## 2 Export du fichier STL depuis SOLIDEDGE :

1. Bouton « application » (en haut à gauche de la fenêtre solidedge) :
2. Bouton « Impression 3D » :
3. Menu Paramètres / Options : Sélectionner les options en rouge :
4. Menu Format d’impression 3D / Exporter :

Pour enregistrer le fichier STL.

Choix du format
de fichier

Pour générer le
fichier STL

Paramètres du
fichiers STL

Choix de la
facettisation

# FICHE N°2 : Démarrage UP Studio

## 3 Présentation du logiciel :

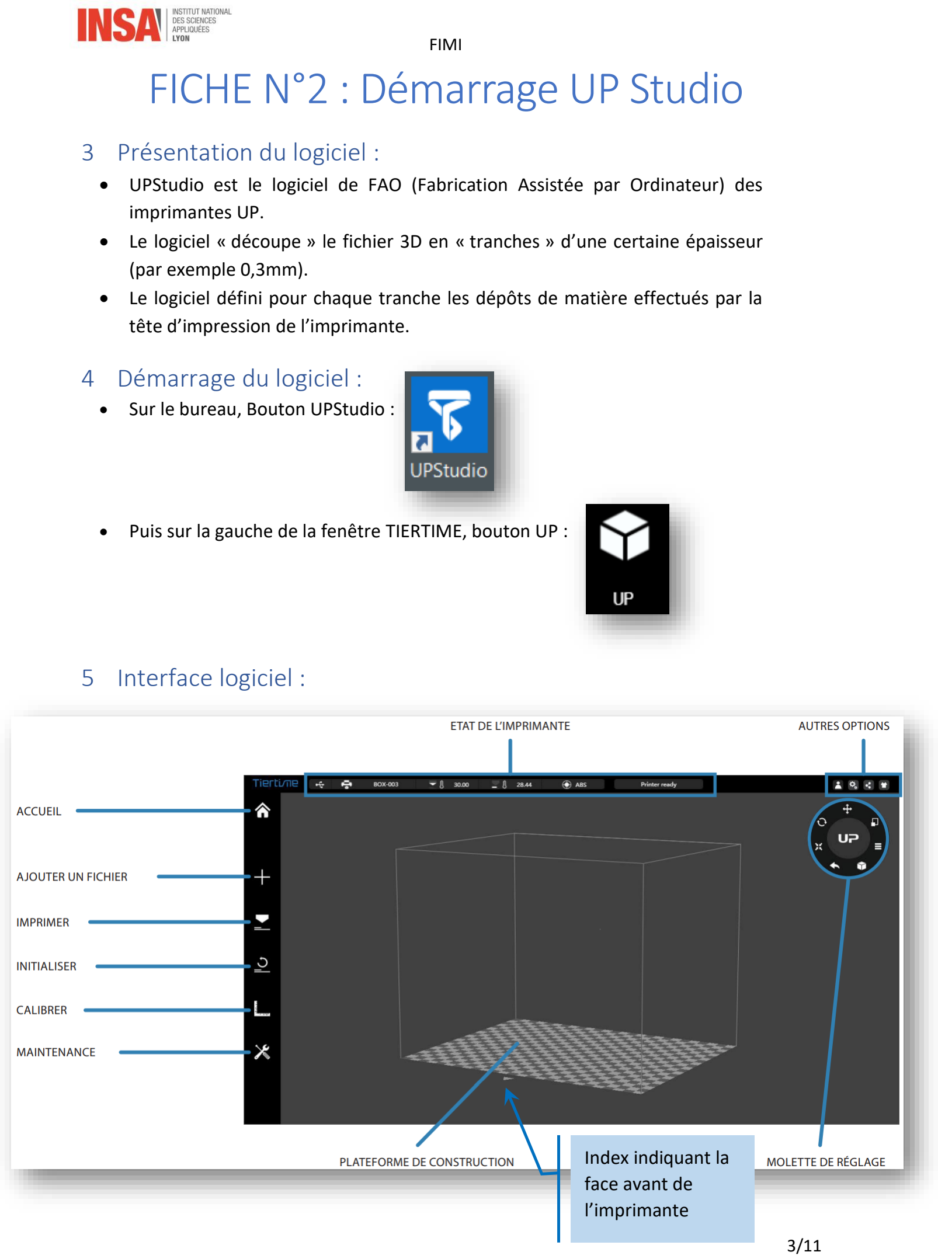
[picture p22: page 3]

- UPStudio est le logiciel de FAO (Fabrication Assistée par Ordinateur) des imprimantes UP.
- Le logiciel « découpe » le fichier 3D en « tranches » d’une certaine épaisseur (par exemple 0,3mm).
- Le logiciel défini pour chaque tranche les dépôts de matière effectués par la tête d’impression de l’imprimante.

## 4 Démarrage du logiciel :

- Sur le bureau, Bouton UPStudio :
- Puis sur la gauche de la fenêtre TIERTIME, bouton UP :

## 5 Interface logiciel :

Index indiquant la
face avant de
l’imprimante

## 6 Import d’un fichier STL :

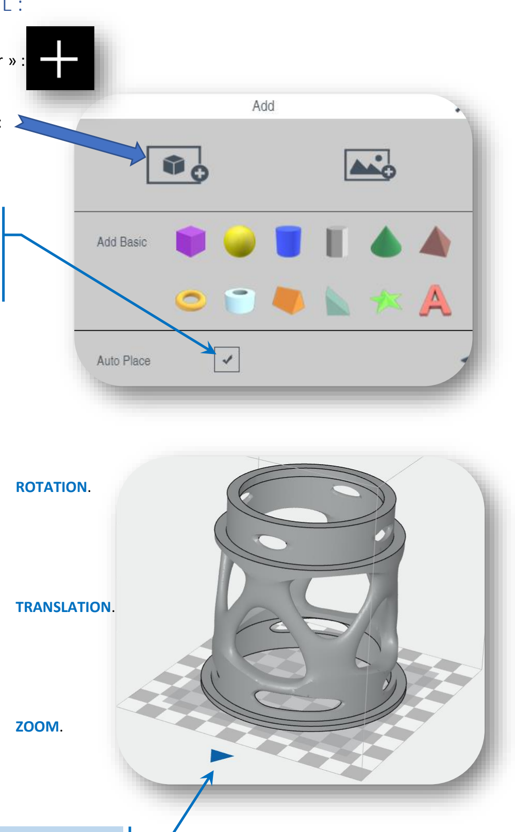
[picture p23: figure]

- Bouton « Ajouter un fichier » :
- Bouton « Add 3D model » :

## 7 Raccourcis souris :

- | Clic gauche : | ROTATION.
- | Clic droit : | TRANSLATION.
- | Molette : | ZOOM.

Option de placement
automatique de la
pièce sur le plateau
de fabrication.

Index indiquant
la face avant de
l’imprimante

# FICHE N°3 : La molette de réglages

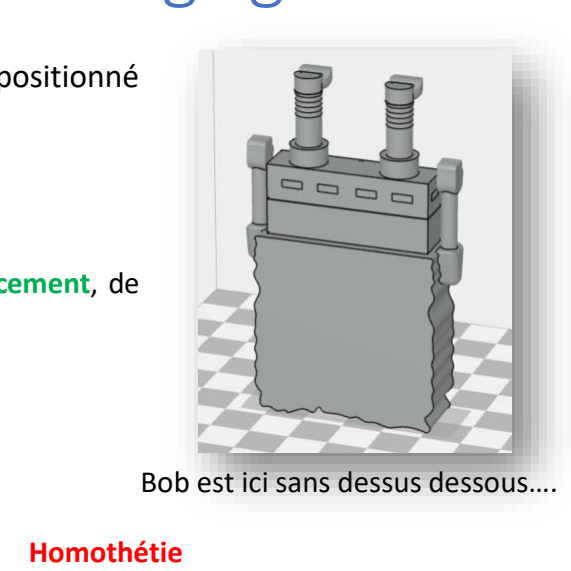
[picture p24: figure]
Homothétie

- A l’import d’un fichier STL, l’objet 3D peut être mal positionné
par rapport à la plateforme de construction.
- La molette de réglage possède des fonctions de déplacement, de visualisation et d’action sur l’objet 3D :
1 | Fonctions additionnelles :
Translation | Bob est ici sans dessus dessous….

Rotation

Vues prédéfinies

Mode d’affichage de l’objet

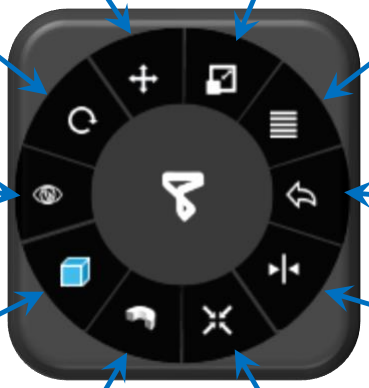
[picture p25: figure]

Vue en coupe

Symétrie

Positionnement automatique

Undo

Fonctions additionnelles

Sauvegarde

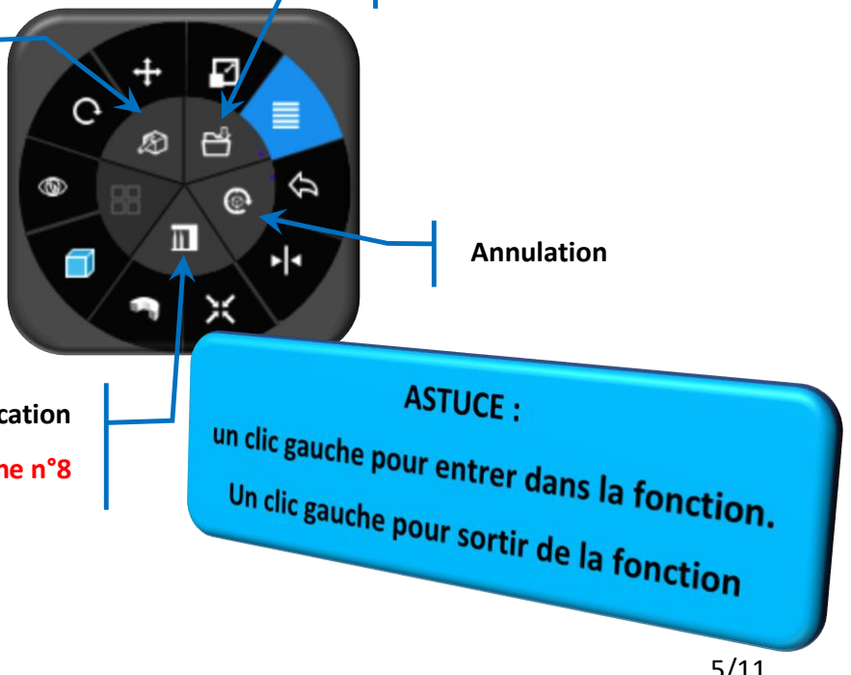
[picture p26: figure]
Annulation

Editeur des supports de fabrication

Voir Fiche n°8

Correction des erreurs
du fichier STL

# FICHE N°4 : Positionnement de l’objet

## 1 Rotation :


## 2 Translation : même principe

Méthode 1

Méthode 2 : Cliquer sur un des axes (qui devient vert) et glisser pour tourner l’objet en temps réel.

Méthode 3 : Cliquer sur le bouton central (« Rotate face to bottom ») puis sélectionner le triangle du fichier stl qui sera positionné face contre la plateforme.

Bob est sur le ventre….

# FICHE N°5 : Informations sur l’objet

## 1 Informations générales : clic gauche sur


## l’objet

## 2 Informations et actions supplémentaires : clic droit sur l’objet

## 3 Vues en coupe :

Autres
propriétés

Méthode : Cliquer sur un des axes (qui devient vert) et glisser pour déplacer la
coupe en temps réel.

# FICHE N°6 : Préparation de l’impression

## 1 Etat de l’imprimante :


### 1.1 Bandeau supérieure :

### 1.2 Préchauffage du plateau :

1 Menu « Maintenance ».

2
3 Durée de chauffage : 15 minutes

4
5 | Bouton « Heat ».
| 1.3 Préparation de l’impression :
1. Menu « Print » :

Matière déclarée

Température du plateau

Température imprimante

Imprimante connectée

Epaisseur des couches de matières

% de remplissage de l’intérieur de l’objet

Qualité de fabrication

Non présence du raft (radeau) si coché, A EVITER !

Non présence de support de fabrication si coché

Démarrage de l’impression

Prévisualisation de l’impression


2. Menu « option » : | sur

Seuil d’angle d’inclinaison de paroi imposant la
présence du support.

Densité du support. Plus la valeur est grande, moins le support est dense.

Préchauffage de
l’imprimante avant
impression.
Option facilitant
l’enlèvement manuel
des supports.

Supports.

Pièce imprimée

Plateau de
fabrication

30°

# FICHE N°7 : Prévisualisation


- La prévisualisation permet de visualiser l’ensemble des couches de matière déposées par l’imprimante.
- Il est possible de visualiser :
- Toutes les couches,
- Un nombre limité de couche,
- Une unique couche.
1. Cliquer sur le bouton « preview du menu « Print » :

En bleu les couches
constitutives de l’objet
imprimé.

En jaune les couches
constitutives des supports.

Curseur de la couche
supérieure visible.

Curseur de la couche
inférieur visible

Les couches visibles sont celles qui sont entre les deux curseurs.

Durée approximative
d’impression

Matériau consommé.

Une seule couche visualisée

# FICHE N°8 : Gestion des supports

Lorsqu’une pièce nécessite des supports de fabrication, il est possible de désactiver les supports que l’on juge inutiles ou pénalisants.

## 1 Exemple de pièce :


## 2 Activation de la fonction gestion des supports :


Les surfaces nécessitant des supports de fabrication apparaissent en jaune.

Editeur des supports de fabrication

On veut des supports ici,

Mais pas ici.


## 3 Fenêtre de paramétrage des supports :

Réglage de l’angle de déport à partir duquel il faut générer des supports.

- Hide Model : Cache la pièce et n’affiche que les surfaces avec des supports.
- Show Support : Affichage des supports en 3D.
- View All : pour afficher / masquer les surfaces avec les supports.

Réglage de la surface minimale en dessous de laquelle on ne génère pas de supports

Activation / désactivation au choix pour chacun des 3 supports de la pièce.

Les supports désactivés
apparaissent en noir.

# FICHE N°9 : Calibration de l’axe Z du plateau d’impression

## ATTENTION : cette opération est délicate. Ne jamais faire de calibration sans avoir prévenu votre professeur et sans

accord de sa part.

## 1 Contexte :

Si les premières couches adhèrent mal au plateau de fabrication, si la pièce se décolle en cours de fabrication, il convient de recalibrer l’axe Z du plateau pour parfaitement positionner ce dernier par rapport à la buse d’extrusion de matière.

intercaler entre la buse et le plateau.; Cliquer sur « Manual ».

## 2 Activation de la fenêtre Calibration :

La procédure consiste à régler manuellement la position du plateau par rapport à la buse d’extrusion en

### 9 points différents. Le réglage se fait via une calle à

## 3 Pour chacun des neufs points de calibration :


- Régler la hauteur du plateau. La bonne hauteur est atteinte quant la buse frotte très légèrement sur la cale de réglage.

Pour monter le plateau.

Pour descendre le plateau.

Pour passer au point
suivant.

La calle en plastique se trouve dans le tiroir du réservoir de la bobine de fil.

### Procéder avec beaucoup de précaution. Un plateau trop haut abime à la fois le plateau (rayure) et la buse qui se

bouche.

Glisser la calle entre le plateau et la buse et « sentir » le jeu en faisant des petits aller retours. Le bon réglage est quand la calle frotte très légèrement sur la buse.

# FICHE N°10 : Organigramme

Lancer le préchauffage de la machine (fiche n°6); fabrication (fiche n°4); Définir les paramètres de fabrication (fiches n°6); Vérifier que le matériau est chargé et s’extrude correctement; Lancer la fabrication (fiche n°6)

## Importer le ou les fichiers STL (fiche n°2)

## Placer la ou les pièces sur le plateau de

## Prévisualiser la fabrication (fiche n°7)

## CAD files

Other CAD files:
CAO_projet/10_equerre.psm
CAO_projet/15_tole_glissiere.psm

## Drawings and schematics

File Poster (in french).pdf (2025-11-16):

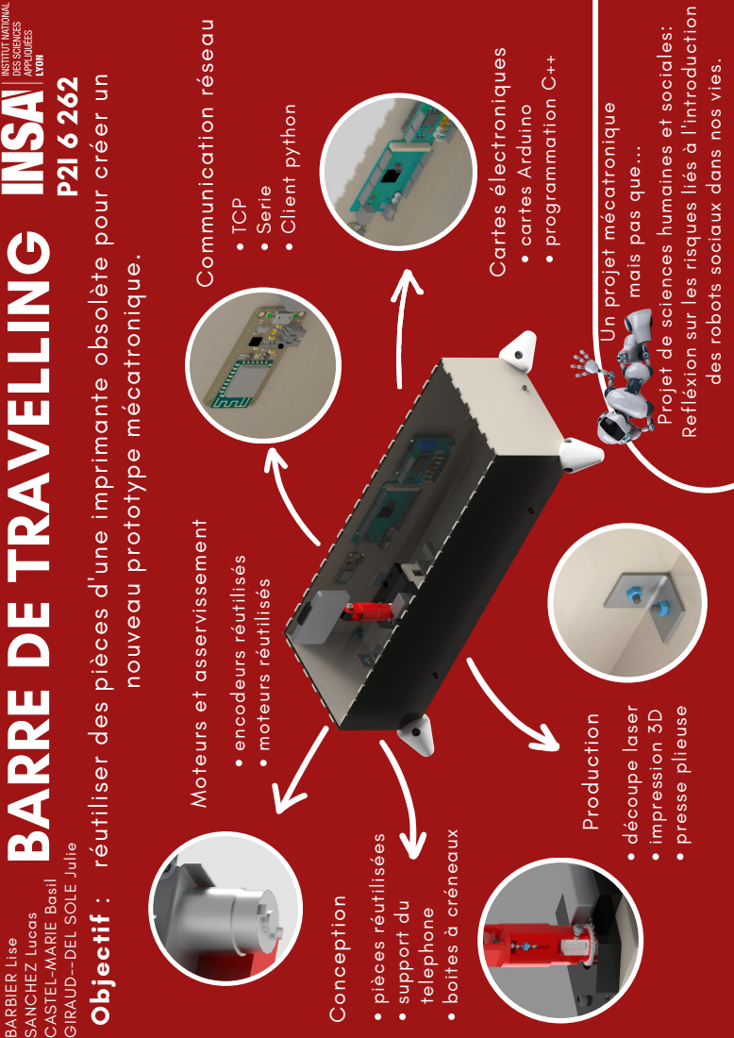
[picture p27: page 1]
Cartes électroniques; Conception; Communication réseau; Objectif :; Production; encodeurs réutilisés; moteurs réutilisés; TCP; Serie; Client python; pièces réutilisées; support du; telephone; boites à créneaux; cartes Arduino; programmation C++; découpe laser; impression 3D; presse plieuse; BARBIER Lise; SANCHEZ Lucas

Refléxion sur les risques liés à l'introduction

Projet de sciences humaines et sociales:

des robots sociaux dans nos vies.

réutiliser des pièces d'une imprimante obsolète pour créer un

Un projet mécatronique

mais pas que...

BARRE DE TRAVELLING

nouveau prototype mécatronique.

Moteurs et asservissement

GIRAUD--DEL SOLE Julie

CASTEL-MARIE Basil

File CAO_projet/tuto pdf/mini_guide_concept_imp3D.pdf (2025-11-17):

## Mini Guide pour la conception de pièces en impression 3D

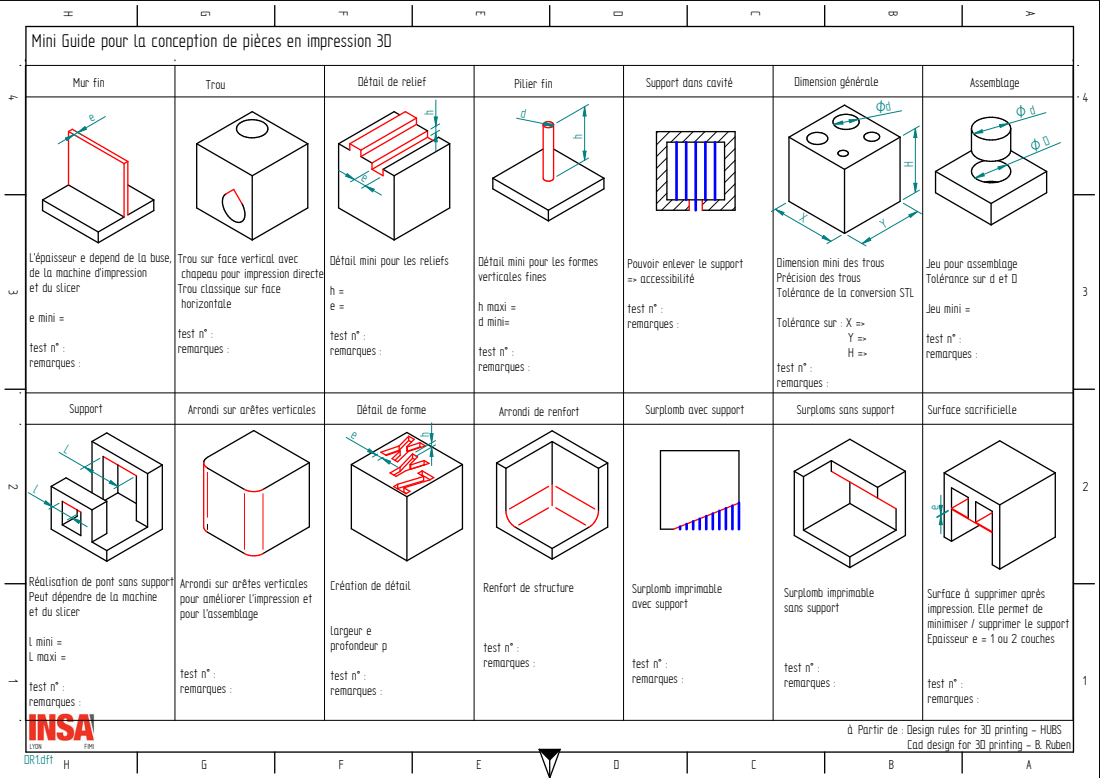
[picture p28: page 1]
DR1.dft; LYON; FIMI; Mur fin; Détail de relief; Pilier fin; Support dans cavité; Dimension générale; Assemblage; Support; Arrondi sur arêtes verticales; Détail de forme; Arrondi de renfort; Surplomb avec support; Surploms sans support; Surface sacrificielle; e mini =; test n° : remarques :; h maxi = d mini=; Tolérance sur : X => Y => H =>; Jeu mini =; l mini = L maxi =; largeur e profondeur p; Surplomb imprimable avec support; Surplomb imprimable sans support; remarques :; test n° :; Trou

L'épaisseur e depend de la buse,
de la machine d'impression
et du slicer

Trou sur face vertical avec
chapeau pour impression directe
Trou classique sur face
horizontale

Détail mini pour les reliefs

Détail mini pour les formes
verticales fines

Dimension mini des trous
Précision des trous
Tolérance de la conversion STL

Pouvoir enlever le support
=> accessibilité

Jeu pour assemblage
Tolérance sur d et D

Réalisation de pont sans support
Peut dépendre de la machine

Arrondi sur arêtes verticales
pour améliorer l'impression et
pour l'assemblage

Création de détail

Renfort de structure

Surface à supprimer après
impression. Elle permet de
minimiser / supprimer le support
Epaisseur e = 1 ou 2 couches

à Partir de : Design rules for 3D printing - HUBS

Cad design for 3D printing - B. Ruben

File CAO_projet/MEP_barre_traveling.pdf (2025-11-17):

# boite à créneaux en MDF NAF et PMMA 3 mm

A | A

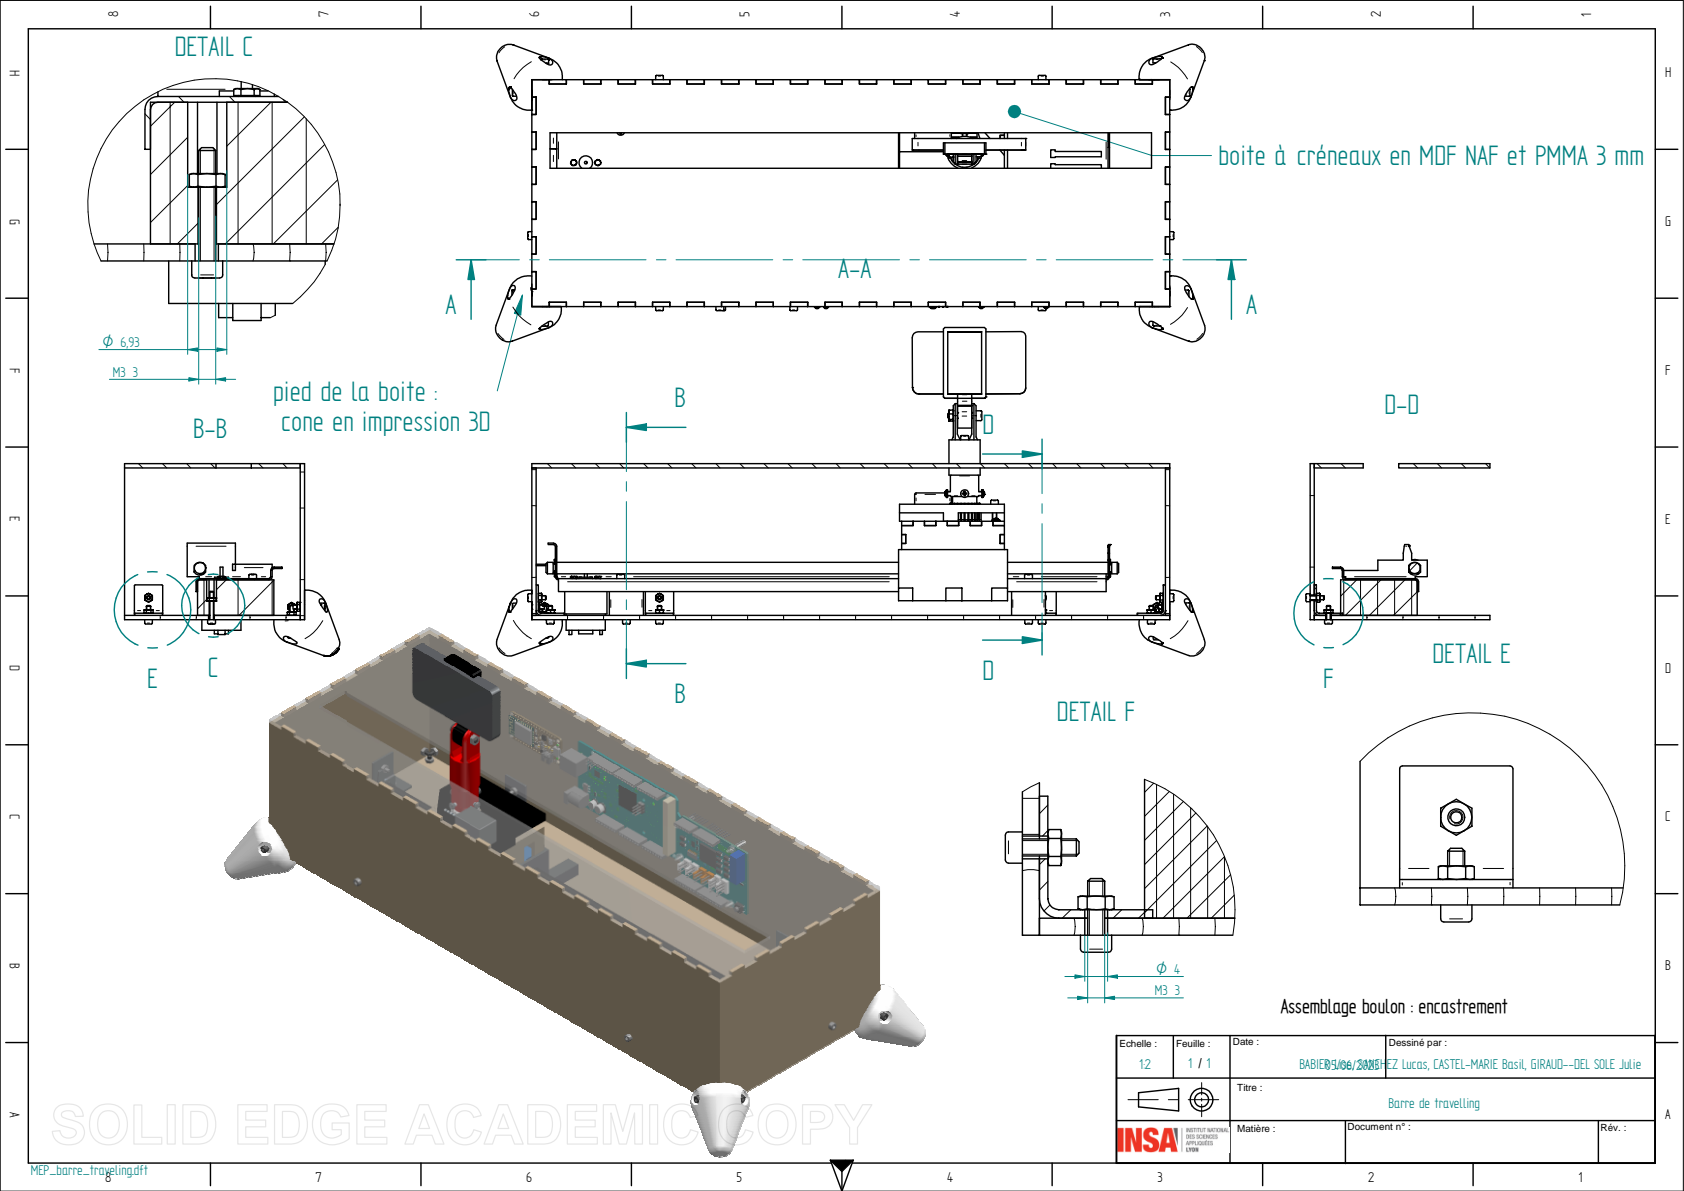
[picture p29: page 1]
MEP_barre_traveling.dft; DETAIL C; DETAIL E; DETAIL F

pied de la boite :
cone en impression 3D

Assemblage boulon : encastrement

Echelle : 1:2 | Feuille : 1 / 1 | Date : BABIER Lise, SANCHEZ Lucas, CASTEL-MARIE Basil, GIRAUD--DEL SOLE Julie 05/06/2023 | Dessiné par :

Titre : Barre de travelling

Matière : | Document n° : | Rév. :

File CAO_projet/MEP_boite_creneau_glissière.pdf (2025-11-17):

A

A-A

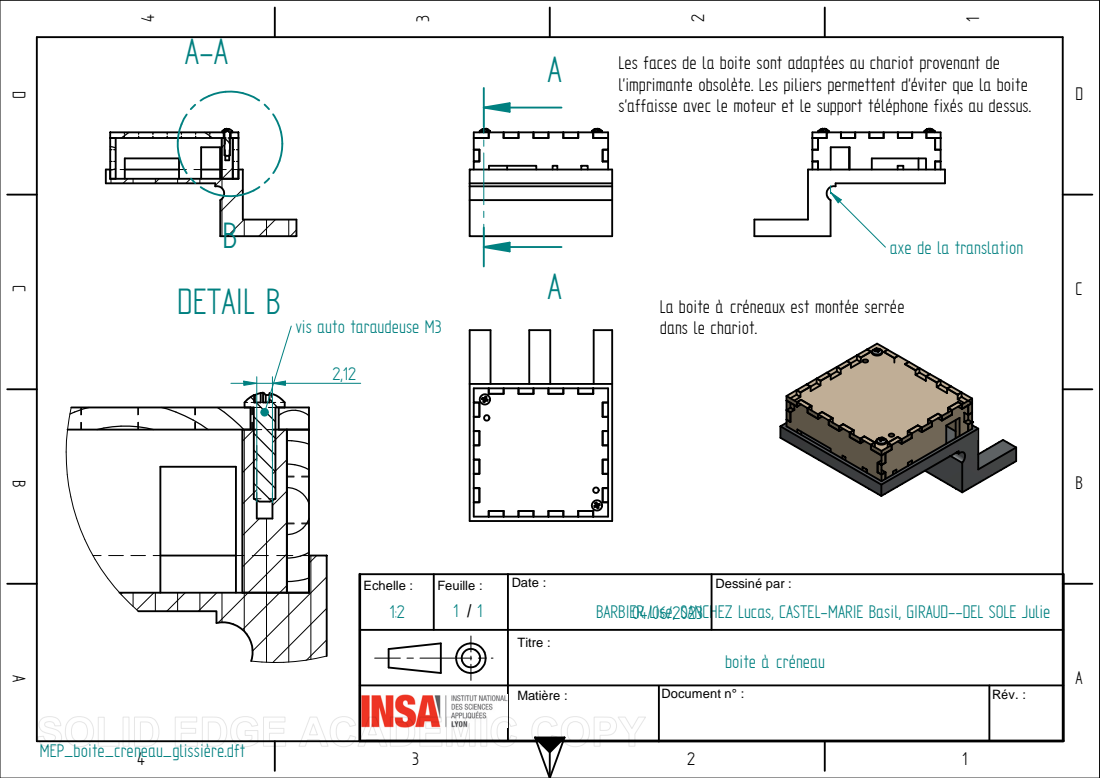
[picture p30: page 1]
MEP_boite_creneau_glissière.dft; DETAIL B

Les faces de la boite sont adaptées au chariot provenant de
l'imprimante obsolète. Les piliers permettent d'éviter que la boite
s'affaisse avec le moteur et le support téléphone fixés au dessus.

axe de la translation

La boite à créneaux est montée serrée
dans le chariot.

vis auto taraudeuse M3

Echelle : 1:2 | Feuille : 1 / 1 | Date : BARBIER Lise, SANCHEZ Lucas, CASTEL-MARIE Basil, GIRAUD--DEL SOLE Julie 04/06/2023 | Dessiné par :

Titre : boite à créneau

Matière : | Document n° : | Rév. :

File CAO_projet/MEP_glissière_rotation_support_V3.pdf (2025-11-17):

A
A-A

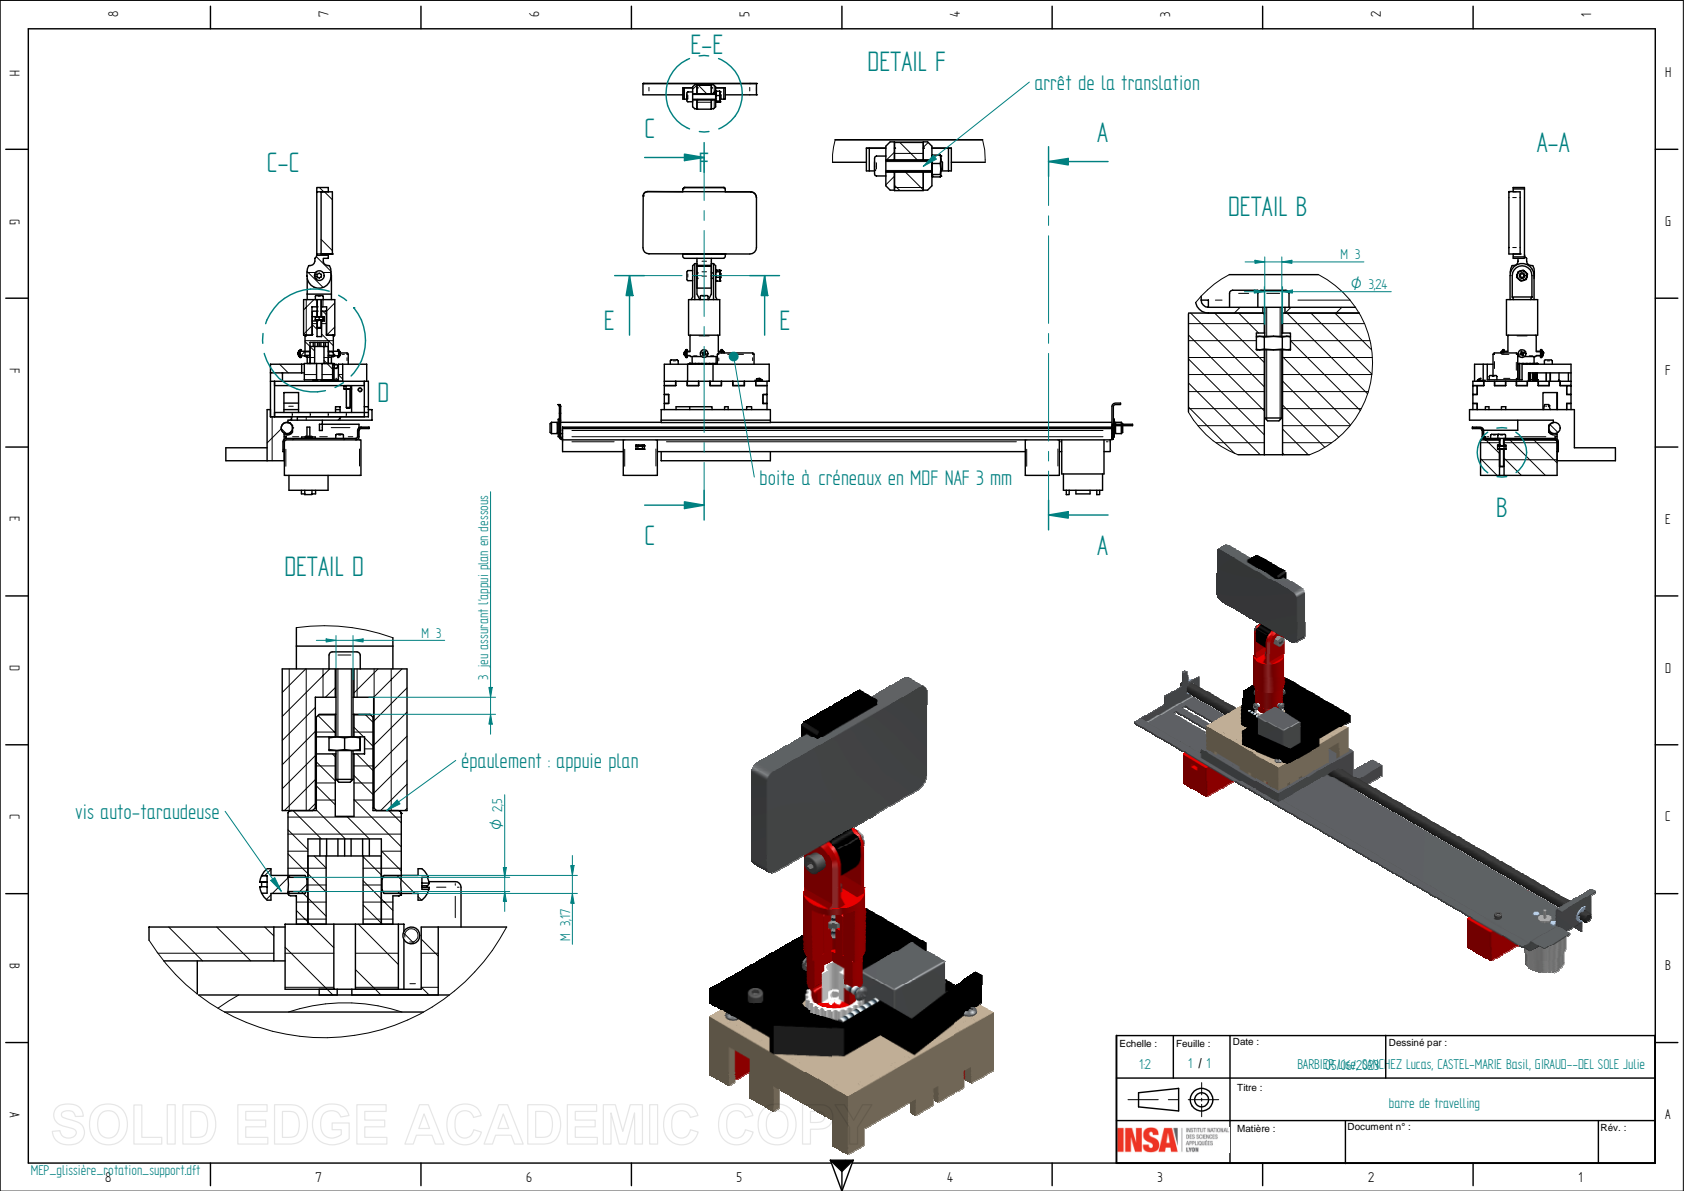
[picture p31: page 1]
MEP_glissière_rotation_support.dft; DETAIL B; DETAIL D; DETAIL F

arrêt de la translation

boite à créneaux en MDF NAF 3 mm

3 jeu assurant l'appui plan en dessous

épaulement : appuie plan

vis auto-taraudeuse

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

Titre : barre de travelling

Matière : | Document n° : | Rév. :

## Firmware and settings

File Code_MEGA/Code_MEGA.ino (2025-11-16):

#include <Encoder.h>
#include <string.h>
#define PINA 47
#define PWMA 45
#define PINB 37
#define PWMB 7
#define FACTEUR_A 224 // 224 signaux/cm
#define FACTEUR_B 14
#define VITESSE_MAX_MOTEUR_A 255
#define VITESSE_MAX_MOTEUR_B 200

Encoder encoder_motor_A(2, 5);
Encoder encoder_motor_B(3, 6);

float kp_moteur_A = 0.6; // voir moodle mecatro pour déterminer proprement kp et ki

float kp_moteur_B = 0.57; // voir moodle mecatro pour déterminer proprement kp et ki

float consigne_en_cm_moteur_A = 5;
int consigne_moteur_A = 0;
long pos_moteur_A = 0;

int erreur_moteur_A = 0 ;
int commande_moteur_A = 0;


float consigne_en_cm_moteur_B = 0;
int consigne_moteur_B;
long pos_moteur_B = 0;

int erreur_moteur_B = 0 ;
int commande_moteur_B = 0;

bool activer_asser_A = false;
bool activer_asser_B = false;
bool tracking = false;

int t0 = 0;
unsigned long t_envoie = 0;
unsigned long t1;
int dt;  //calcul de dt



void setup() {
  // put your setup code here, to run once:
  Serial.begin(115200);
  Serial1.begin(115200);
  pinMode(PINA, OUTPUT);
  pinMode(PWMA, OUTPUT);
  pinMode(PINB, OUTPUT);
  pinMode(PWMB, OUTPUT);


  Serial1.setTimeout(10);
  calibration();
  //consigne_moteur_A = verification_consigne(consigne_en_cm_moteur_A);
  Serial.println("Bienvenue, annonce la commande");
}

void loop() {

  //Serial.print(String(pos_moteur_A) + " ; ");
  pos_moteur_A = encoder_motor_A.read();
  pos_moteur_B = encoder_motor_B.read();
  /*if (abs(pos_moteur_B) > 360){
    encoder_motor_B.write(0);
    pos_moteur_B = encoder_motor_B.read();
    }*/
  if (Serial1.available()) {

    String commande = Serial1.readStringUntil(';');
    commande.trim();
    Serial.println("commande recu : " + commande);

    if (commande.startsWith("/TR")) {
      tracking = true;
      activer_asser_A = true;
      activer_asser_B = false;
      consigne_moteur_A = pos_moteur_A;
      consigne_moteur_B = pos_moteur_B;

      kp_moteur_A = 0.5; // spécial pour le tracking
      kp_moteur_B = 0.57;

      commande = commande.substring(3);
      commande.trim();

      if (commande.startsWith("/A") and (pos_moteur_A < 29 * FACTEUR_A) and pos_moteur_A > 50 ) {
        commande = commande.substring(2);
        commande.trim();
        erreur_moteur_A = commande.toInt();
      }
      else {
        commande = commande.substring(2);
        commande.trim();
        erreur_moteur_B = commande.toInt();
      }

    }

    else if (commande.startsWith("/TL")) {
      tracking = false;
      String temp = "";
      //activer asservissement moteur a et b
      activer_asser_A = true;
      activer_asser_B = false;

      kp_moteur_A = 1.0; // spécial pour l'asservissement
      kp_moteur_B = 0.57;

      commande = commande.substring(3);
      commande.trim();

      temp = commande;

      commande = commande.substring(0, 7);
      commande.trim();
      consigne_en_cm_moteur_A = commande.toFloat();

      temp = temp.substring(7);
      temp.trim();
      consigne_en_cm_moteur_A = temp.toFloat();

      consigne_moteur_A = verification_consigne(consigne_en_cm_moteur_A);
      consigne_moteur_B = consigne_en_cm_moteur_B * FACTEUR_B;
    }


    else if (commande.startsWith("/MOTORA")) {
      tracking = false;
      activer_asser_A = false;
      activer_asser_B = false;
      commande = commande.substring(7);
      commande.trim();

      commande_moteur_A = commande.toInt();

      //Serial.print(commande_moteur_A);
      if (pos_moteur_A / FACTEUR_A < 29 - (0.01 * abs(commande_moteur_A)) and commande_moteur_A > 0) {
        moteur_A(commande_moteur_A);
      }
      else if (pos_moteur_A / FACTEUR_A > 0.01 * abs(commande_moteur_A) and commande_moteur_A < 0) {
        moteur_A(commande_moteur_A);
      }
      else {
        moteur_A(0);
      }
    }


    else if (commande.startsWith("/MOTORB")) {
      tracking = false;
      activer_asser_A = false;
      activer_asser_B = false;
      commande = commande.substring(7);
      commande.trim();

      commande_moteur_B = commande.toInt();

      //Serial.print(commande_moteur_B);
      moteur_B(commande_moteur_B);


    }

    else if (commande == "Calibration") {
      tracking = false;
      activer_asser_A = false;
      activer_asser_B = false;
      Serial1.print("/ORDI La barre est en cours de calibration\n");
      calibration();
      consigne_moteur_A = 0;
      Serial1.print("/ORDI La barre est calibrée !\n");
    }
  }



  t1 = millis(); //Temps en secondes donc /1000
  //dt = t1 - t0 ;

  if (t1 - t_envoie > 300) {
    Serial1.print("/ORDI /POSA " + String(pos_moteur_A / FACTEUR_A) + "\n");
    delay(100);
    Serial1.print("/ORDI /POSB " + String(pos_moteur_B / FACTEUR_B) + "\n");
    t_envoie = t1;
  }

  if (activer_asser_A) {
    if (not tracking) {
      erreur_moteur_A = consigne_moteur_A - pos_moteur_A;
    }
    commande_moteur_A = kp_moteur_A * erreur_moteur_A;
    moteur_A(commande_moteur_A);
  }

  if (activer_asser_B) {
    erreur_moteur_B = consigne_moteur_B - pos_moteur_B;

    commande_moteur_B = kp_moteur_B * erreur_moteur_B ;
    moteur_B(commande_moteur_B);
  }


  t0 = t1;
}

void calibration() { // positionnement du moteur à 0
  int t_actuel = 0;
  int t_depart = 0;
  long pos_actuel = 0;
  bool reset_time = false;
  long pos_precedent = 0;
  bool verif_temps = false;

  encoder_motor_B.write(0);
  while (not reset_time) {
    moteur_A(-150); // avance jusqu'à ne plus pouvoir
    t_actuel = millis();
    pos_actuel = encoder_motor_A.read();
    Serial.println(pos_actuel);
    if (pos_actuel == pos_precedent) {
      if (not verif_temps) {
        t_depart = millis(); // on lance le chrono de vérification de position constante
        verif_temps = true;
      }
      if (t_actuel - t_depart > 100) { // si la position reste la même pendant plus de 50 ms
        encoder_motor_A.write(0);
        reset_time = true; // calibration terminée
      }
    }
    else {
      verif_temps = false; // si la position n'est pas égale pendant au moins 50 ms alors on arrête le chrono et on continue
    }
    pos_precedent = pos_actuel;
  }
  moteur_A(0);
}

int distance_cm(float distance) { // convertit nb de signaux en distance 6900 signaux pour 29cm
  int pos = distance * FACTEUR_A;
  return (pos); // il suffit d'inverser les pin 2 et 3 popur mettre en positif
}

int verification_consigne(int consigne_en_cm) {
  if (consigne_en_cm > 29) {
    consigne_en_cm = 29;
  }
  else if (consigne_en_cm < 0) {
    consigne_en_cm = 0;
  }

  return distance_cm(consigne_en_cm);
}

void moteur_A(int vitesse) {  // vitesse de -255 à 255 moteur 12 V
  if (vitesse > 0) {
    digitalWrite(PINA, HIGH);
  }
  else {
    digitalWrite(PINA, LOW);
  }
  vitesse = abs(vitesse);
  if (vitesse > VITESSE_MAX_MOTEUR_A) {
    vitesse = VITESSE_MAX_MOTEUR_A;
  }
  analogWrite(PWMA, vitesse);
}

void moteur_B(int vitesse) {  // vitesse de -128 à 128 car moteur 6V
  if (vitesse > 0) {
    digitalWrite(PINB, HIGH);
  }
  else {
    digitalWrite(PINB, LOW);
  }
  vitesse = abs(vitesse);
  if (vitesse > VITESSE_MAX_MOTEUR_B) {
    vitesse = VITESSE_MAX_MOTEUR_B;
  }
  analogWrite(PWMB, vitesse);
}

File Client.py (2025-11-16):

import cv2
import os
import tkinter as tk
from PIL import Image, ImageTk
from tkinter import ttk
import time
import socket
from threading import Thread
import numpy as np


source = 1  #indiquer source de la vidéo à afficher
PORT = 5000
IP = "192.168.137.137"




class App :
    def __init__(self, source) :
        self.mainWindow = tk.Tk()
        self.mainWindow.title('essai')
        self.IP = ""
        self.id_affichage = None
        self.id_etat_video = None
        self.pair = 0
        self.fenetre_time_laps = None
        self.etat_connexion = False
        self.choix_scenario = tk.StringVar()
        self.choix_scenario.set("Time laps")
        self.position_moteur_A = 0
        self.position_moteur_B = 0
        self.ancienne_pos_A = 0
        self.ancienne_pos_B =0
        self.compteur_dossier_TL = 0
        self.premier_clic = True
        self.le_socket = socket.socket(socket.AF_INET, socket.SOCK_STREAM)
        self.mainWindow.attributes('-fullscreen', True)
        self.mainWindow.bind("<KeyPress-Escape>", self.quit)
        self.camera = MyCamera(source)
        self.color=100
        self.lo=np.array([self.color-5, 100, 50])
        self.hi=np.array([self.color+5, 255,255])
        self.color_info=(0, 0, 255)
        self.pret = False
        self.reconnaissance_activer = False
        self.t0=0

        
        self.widgets(self.mainWindow)
        self.timer_etat_video()
        
        
        

    def widgets(self, root) :

        self.textIp = tk.Label(root, text = "Entrez IP ESP :")
        self.textIp.place(x = 350, y = 175)

        self.entre_ip = tk.Entry(root, width=40)
        self.entre_ip.place(x = 435, y = 175)
        self.entre_ip.insert(0, "192.168.137.148")

        self.connect = tk.Button(root, text= "Connecter", background = 'yellow')
        self.connect.place(x = 690, y = 170 )
        self.connect.bind('<Button-1>', self.connexion)

        self.etat_connecte = tk.Label(root, text = "Non connecté")
        self.etat_connecte.place(x = 770, y = 175)

        self.bouton_video = tk.Button(root, background = 'yellow', text = 'afficher Vidéo', width = 40)
        self.bouton_video.place(x = 50, y = 130)
        self.bouton_video.bind('<Button-1>', self.affichage_window_camera)

        self.bouton_quitter = tk.Button(root, background = 'yellow', text = 'quitter', width = 40)
        self.bouton_quitter.place(x = 50, y = 170)
        self.bouton_quitter.bind('<Button-1>', self.destroy)

        self.aller_droite = tk.Button(root, background = 'yellow', text = 'Aller à droite', width = 20, command=self.translation_droite, repeatdelay=1, repeatinterval=1000)
        self.aller_droite.place(x = 1360, y = 200)
        self.aller_droite.bind('<ButtonRelease-1>', lambda event: self.ralentir(event, "A"))

        self.aller_gauche = tk.Button(root, background = 'yellow', text = 'Aller à gauche', width = 20, command=self.translation_gauche, repeatdelay=1, repeatinterval=1000)
        self.aller_gauche.place(x = 1200, y = 200)
        self.aller_gauche.bind('<ButtonRelease-1>', lambda event: self.ralentir(event, "A"))

        self.touner_gauche = tk.Button(root, background = 'yellow', text = 'Tourner à gauche', width = 20, command=self.rotation_gauche, repeatdelay=1, repeatinterval=1000)
        self.touner_gauche.place(x = 1200, y = 230)
        self.touner_gauche.bind('<ButtonRelease-1>', lambda event: self.ralentir(event, "B"))


        self.touner_droite = tk.Button(root, background = 'yellow', text = 'Tourner à droite', width = 20, command=self.rotation_droite, repeatdelay=1, repeatinterval=1000)
        self.touner_droite.place(x = 1360, y = 230)
        self.touner_droite.bind('<ButtonRelease-1>', lambda event: self.ralentir(event, "B"))

        self.affichage_message = tk.Label(root, text = "Message recu de l'arduino :")
        self.affichage_message.place(x = 1280, y = 270)

        self.affichage_pos_A = ttk.Progressbar(root, orient = "horizontal", length = 200, mode = 'determinate', value= 0)
        self.affichage_pos_A.place(x = 1300, y = 320)

        self.message_pos_A = tk.Label(root, text = "Position transversale Caméra : ").place(x = 1130, y = 320)

        self.btn_calibration = tk.Button(root, background = 'yellow', text = 'Calibration', width = 20, command = self.calibration)
        self.btn_calibration.place(x = 1280, y = 150 )
        
        self.affichage_vitesse_motor_A = tk.Label(root, text = "Vitesse de la translation :").place(x = 1130, y = 370)
        self.curseur_vitesse_motor_A = tk.Scale(root, from_ = 95, to = 255, length = 200, orient='horizontal')
        self.curseur_vitesse_motor_A.place(x = 1298, y = 350)

        self.affichage_vitesse_motor_B = tk.Label(root, text = "Vitesse de la rotation :").place(x = 1130, y = 415)
        self.curseur_vitesse_motor_B = tk.Scale(root, from_ = 100, to = 200, length = 200, orient='horizontal')
        self.curseur_vitesse_motor_B.place(x = 1298, y = 395)
        

        self.titre_scenario = tk.Label(root, text = "Création scénario")
        self.titre_scenario.place(x = 1280, y = 470)

        self.affichage_choix_temps = tk.Label(root, text= "Choisir durée scénario : ").place(x = 1130, y = 500)
        self.choix_temps = tk.Spinbox(root, from_= 60, to = 900, width = 10)
        self.choix_temps.place(x = 1300, y = 500)

        self.affichage_choix_rotation = tk.Label(root, text= "Choisir rotation scénario : ").place(x = 1130, y = 535)
        self.choix_rotation = tk.Spinbox(root, from_= 1, to = 720, width = 10)
        self.choix_rotation.place(x = 1300, y = 535)

        self.lancer_scenario = tk.Button(root, text= "Lancer le scnénario", bg = 'yellow' , width = 20)
        self.lancer_scenario.place(x = 1280,y= 610)
        self.lancer_scenario.bind('<Button-1>', self.scenario)

        self.time_laps = tk.Radiobutton(root, text="Time laps", variable=self.choix_scenario, value="Time laps")
        self.time_laps.place(x = 1400, y = 500)

        self.scenario_video = tk.Radiobutton(root, text="Vidéo", variable=self.choix_scenario, value="Vidéo")
        self.scenario_video.place(x = 1400, y = 535)

        self.affichage_choix_dt = tk.Label(root, text= "Delta t entre photos: ").place(x = 1130, y = 570)
        self.choix_dt = tk.Spinbox(root, from_= 1, to = 60, width = 10)
        self.choix_dt.place(x = 1300, y = 570)

        self.bouton_photo = tk.Button(root, text = "Prendre une photo", command = lambda: self.camera.prendre_photo("Photos/Photo "+str(self.camera.compteur_photo)+" .jpg"),  bg = 'yellow', width = 20)
        self.bouton_photo.place(x = 250, y = 825)

        self.bouton_photo = tk.Button(root, text = "Prendre une vidéo", command = lambda: self.camera.prendre_video("Vidéos/Vidéo "+str(self.camera.compteur_video)+" .avi"),  bg = 'yellow', width = 20)
        self.bouton_photo.place(x = 450, y = 825)

        self.etat_video = tk.Label(root, text="")
        self.etat_video.place(x = 675, y = 825)
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

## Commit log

2025-11-16 Add videos and docs and test codes
    [schéma cablage.fzz, schéma cablage.kicad_pcb, schéma cablage.kicad_sch]
2025-11-17 CAO adding
    [10_equerre.psm, 15_tole_glissiere.psm, A1_boite_générale.cfg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]
